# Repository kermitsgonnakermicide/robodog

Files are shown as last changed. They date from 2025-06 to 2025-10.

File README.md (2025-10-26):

# OpenDoggo

A quadruped robot platform running ROS2 Humble on a Raspberry Pi 4 with 3DOF legs and an optional SLAM capability via either Lidar and stereo vision.<br>

**Design**<br>
I started off by CADing the entire thing, keeping in mind that this will be an actively developed platform — no fancy covers, just raw plate and servo mounts.<br>
Went with a central plate that houses all the power distribution + electronics, and simple oval-style end mounts for the legs.<br>
The legs are 3DOF and use MG996R servos — cheap and decently powerful<br>
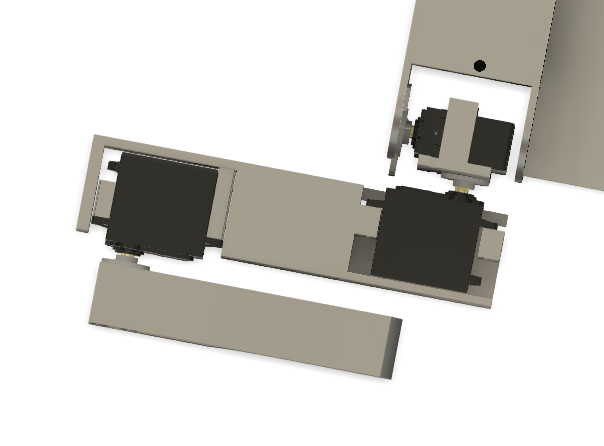
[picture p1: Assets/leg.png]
leg
<br>

Later added a lid to keep things _mostly_ protected.<br>
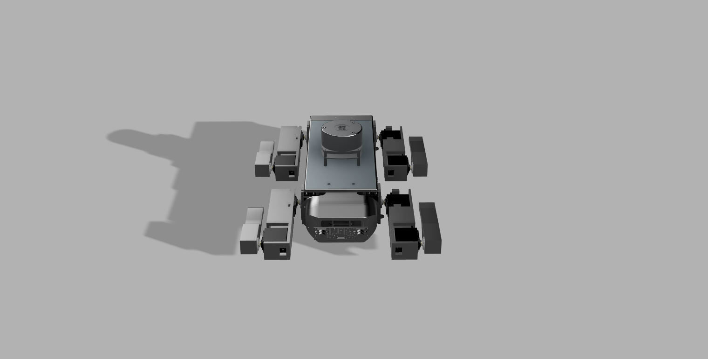
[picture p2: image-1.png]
<alt text>
<br>

**Electronics**<br>
I made a custom, 63 by 48 mm PCBA that has 5 major functions:<BR>

- step down power from my 4s 14.8v lipo battery to 5v<br>
- step up power from 5v to 7v to effectively power my servoes
- output that 5v power to my raspi on USB<br>
- control my servoes with a PCA9685<br>
- one of the best IMUs, the BNO086 for optimizing gait<br>
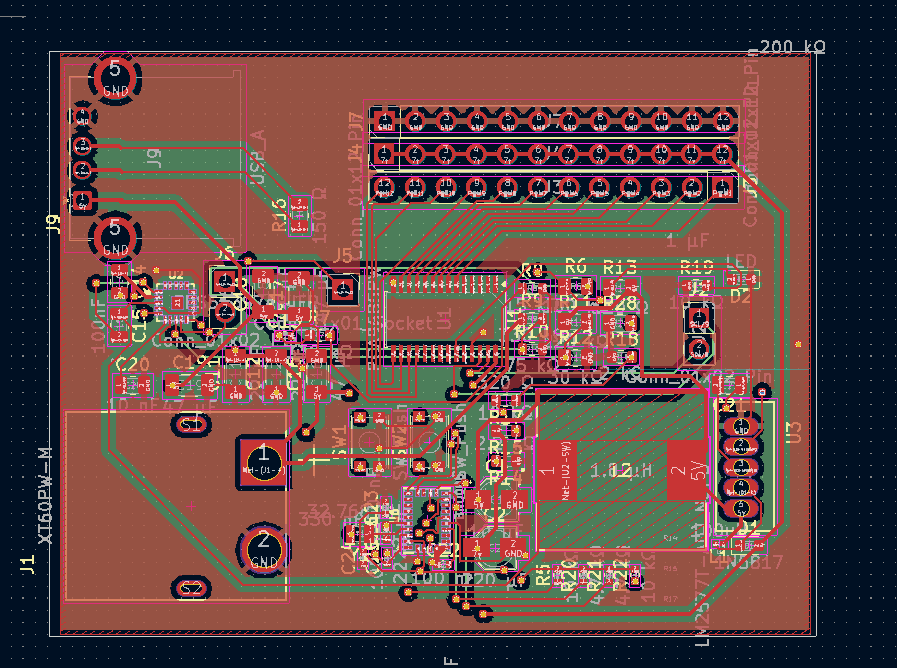
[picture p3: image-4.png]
  
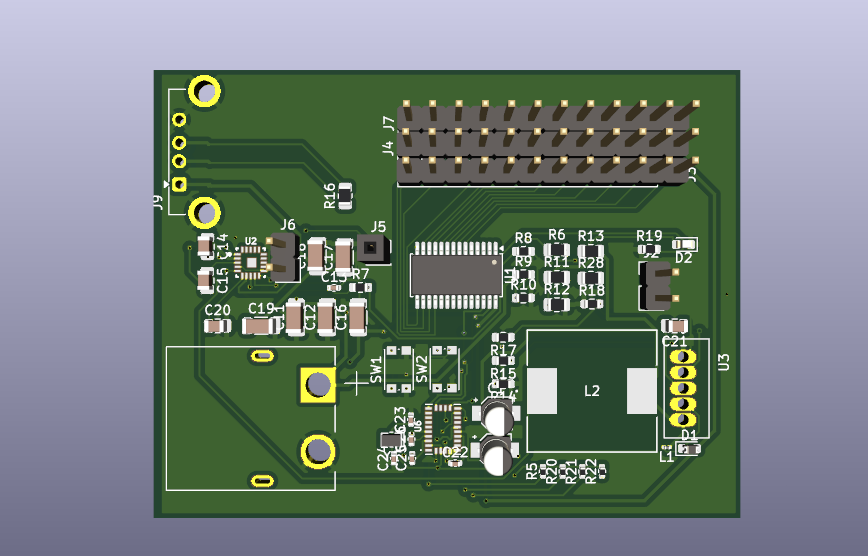
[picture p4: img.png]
  
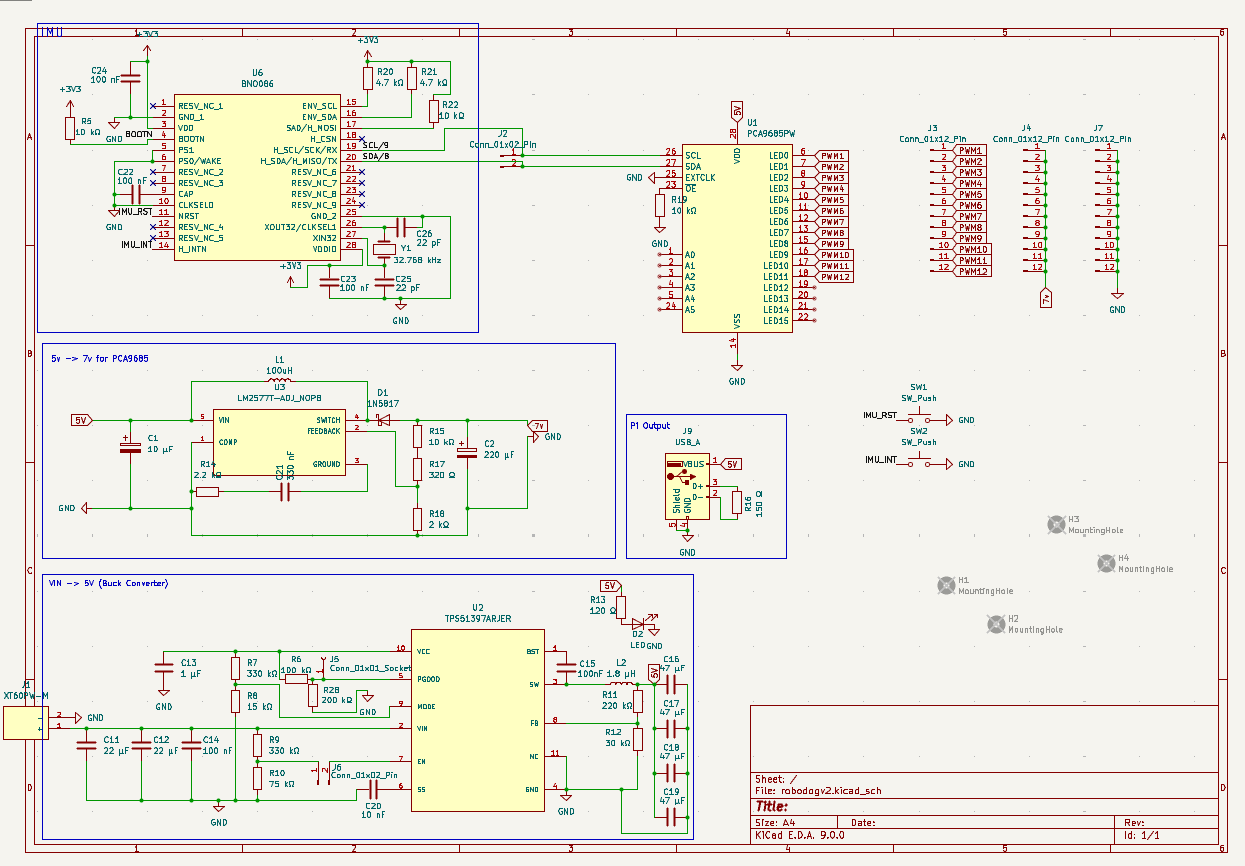
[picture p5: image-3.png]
  

**Firmware**<br>
**ROS Packages**  
The whole ROS workspace is structured into 4 main packages:

- **servo_driver**  
  The hardware interface layer. This node communicates with one or more PCA9685 boards via I2C to send position signals to each servo motor. It exposes a simple ROS2 service + topic interface that allows other nodes to command joint angles (in degrees or radians). It also implements basic limits, deadzone filtering, and optional torque hold toggling. Each servo is mapped to a specific joint name and leg index.

- **leg_walker**  
  This package does all the IK heavy lifting. It:

  - Subscribes to target paw positions (either via a `/cmd_paw_pos` topic or internal walking scripts)
  - Solves 3DOF inverse kinematics per leg (coxa, femur, tibia)
  - Publishes joint angles to the `servo_driver`
  - Supports gait generation — currently just a trot gait, but it's modular
  - Includes walking state machines, leg timing, and paw trajectory interpolation
    This is where all the math happens.

- **slam_yplidar_x2**  
  SLAM package using the YDLidar X2. It launches:

  - A serial connection to the Lidar via `ydlidar_ros2_driver`
  - `slam_toolbox` in synchronous mode
  - RViz config for map + robot visualization
    Outputs a 2D occupancy map and robot pose estimate. Currently uses fake odom + map merging but will be upgraded later with IMU + gait odometry.

- **slam_stereo_picams**  
  Alternate SLAM method using two Raspberry Pi cameras as a stereo pair (synced via GPIO trigger). It:
  - Captures stereo image pairs
  - Runs semi-global block matching or other stereo algorithm (WIP: OpenCV + rtabmap)
  - Feeds into `rtabmap_ros` for visual SLAM
  - Outputs a 3D point cloud and pose estimate
    This is mostly experimental right now but promising for GPS-denied areas and outdoor mapping.

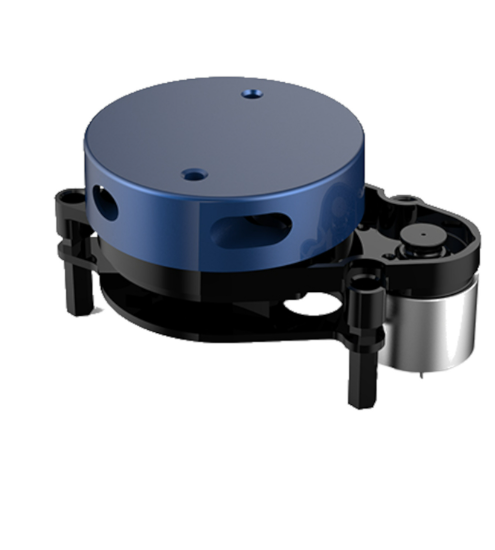
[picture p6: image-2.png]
alt text>
<br>

**NOTE**: Reusing the lipo battery from a diff project<br>

**BOM**
|ITEM |QTY|TOTAL |SRC |NOTES |
|---|---|---|---|---|
|Raspberry Pi 5 8GB |1 |94.82 |https://www.silverlineelectronics.in/collections/raspberry-pi-5-official-accessories/products/raspberry-pi-5-model-b-8gb-ram |I require an 8GB because I dont just need to use ROS - within it, I also need to do SLAM(even more computationally expensive)|
|RPi 5 Active Cooler |1 |5.27 |https://www.silverlineelectronics.in/collections/raspberry-pi-cooling-tech | |
|SD Card |1 |6.93 |https://www.amazon.in/SAMSUNG-Adaptor-Expanded-Storage-MB-MC64SA/dp/B0CXJ5Q222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,aps,226&sr=8-3&th=1| |
|Waveshare Stereo Camera|1 |47.76 |https://hubtronics.in/imx219-83-stereo-camera | |
|YDLIDAR X2 |1 |60.99 |https://www.electronicscomp.com/ydlidar-x2-360-degree-ros-scanner-for-navigation-collision-avoidance-8m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 | |
|PCBA |1 |129 |https://hc-cdn.hel1.your-objectstorage.com/s/v3/cd5c9a744fc6b144acc7592c6a4c4ebfb7888e05_image.png |LionCircuits |
|XT60PW-m |1 |1.91 |https://www.drkstore.in/amass-xt60pw-f20-connector/ |Not available to procure on LionCircuits, also including delivery |
|USB A |1 |0.17 |https://robu.in/product/u221-041n-1wr69-s5-xkb-1-5a-1-4p-female-40%e2%84%8385%e2%84%83-type-a-plugin-usb-connectors-rohs/ |Will cover myself, not available on LionCircuits |
|MG996R |12 |48.62 |https://sharvielectronics.com/product/mg996r-metal-gear-servo-motor/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 | |
| | | | | |
| | | | | |
| | |395.47| | |
**NOTE: Will also cover the MG996s myself to ensure that i'm under budget**

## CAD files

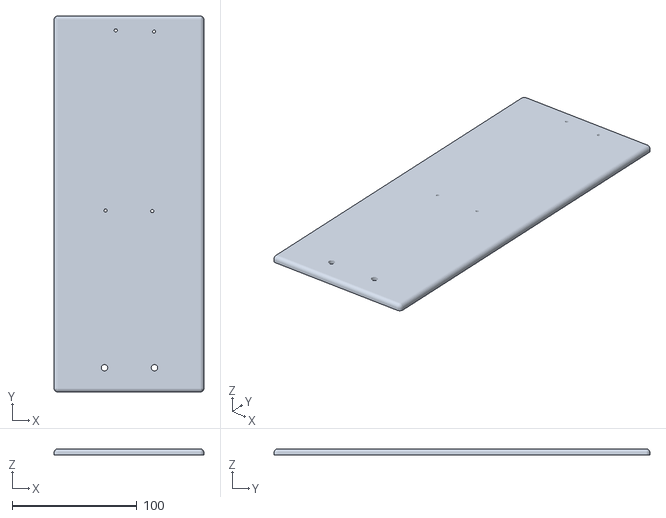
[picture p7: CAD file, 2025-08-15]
Production/Prints/MAINBODY_TOPPLATE.stl
120.0 x 301.0 x 5.00

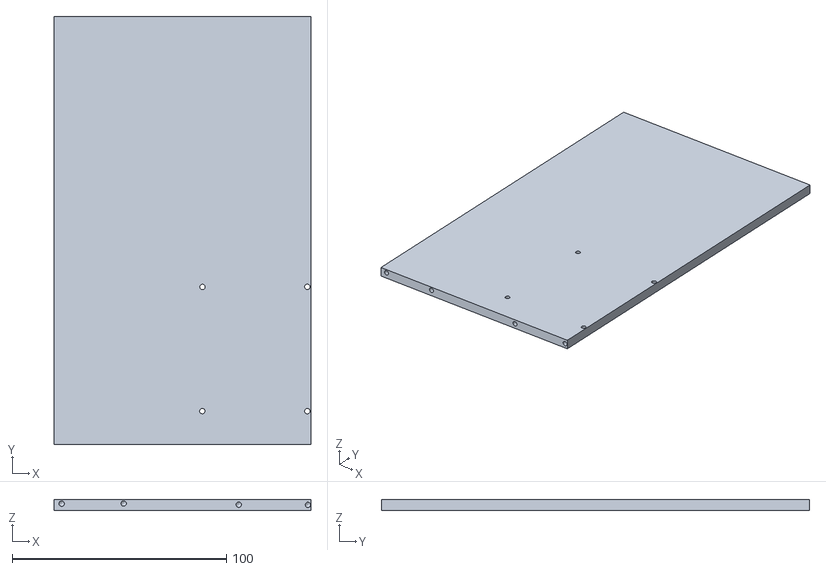
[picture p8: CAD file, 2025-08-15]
Production/Prints/MAINBODY_BOTTOMPLATE.stl
120.0 x 200.0 x 5.00

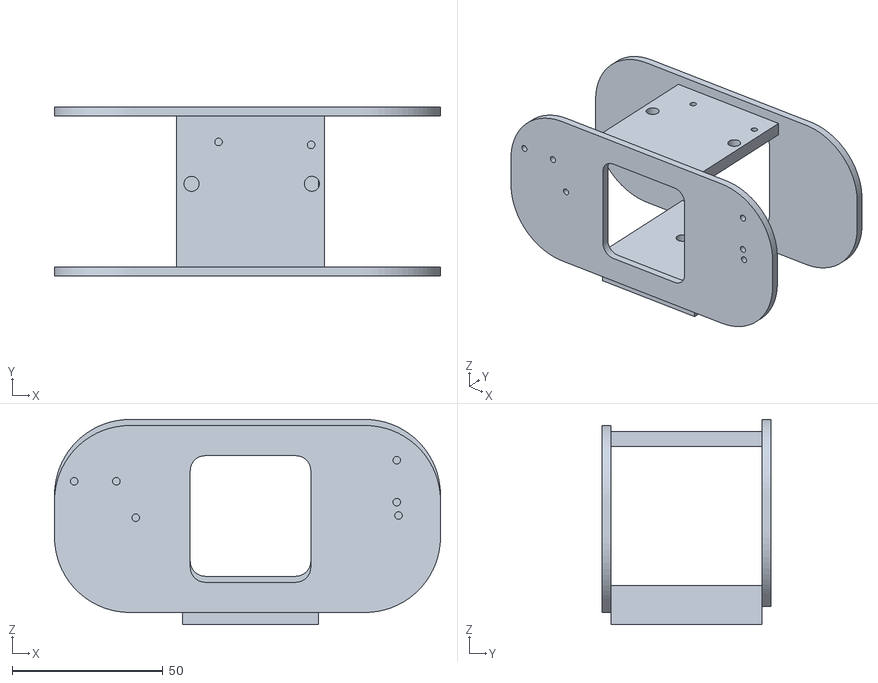
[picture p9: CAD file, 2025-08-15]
Production/Prints/MAINBODY_BACKMOUNTING.stl
128.0 x 56.0 x 68.0

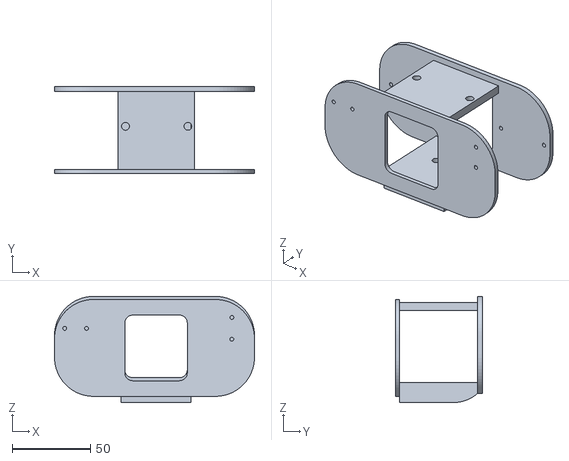
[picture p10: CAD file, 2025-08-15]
Production/Prints/MAINBODY_FRONTHING.stl
128.0 x 55.6 x 68.0

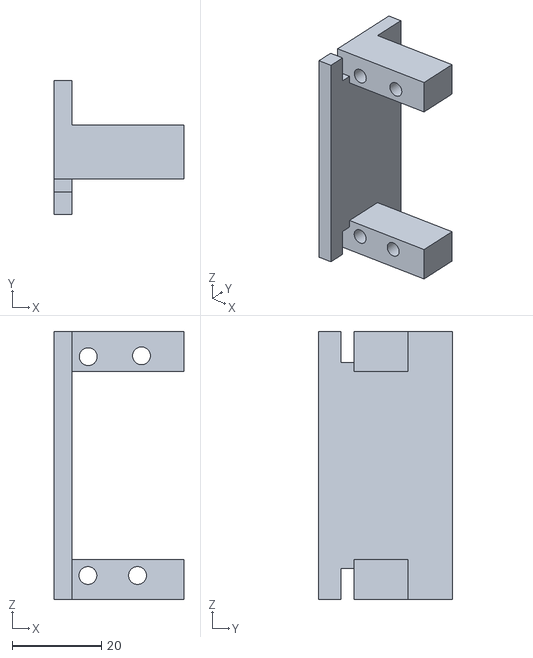
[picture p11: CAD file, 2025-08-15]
Production/Prints/LJ1(x4).stl
29.0 x 30.0 x 60.0

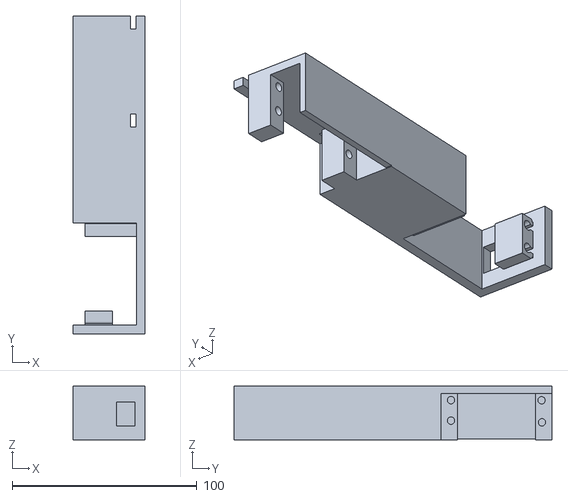
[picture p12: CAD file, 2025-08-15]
Production/Prints/LJ2(x4).stl
39.0 x 172.0 x 29.0

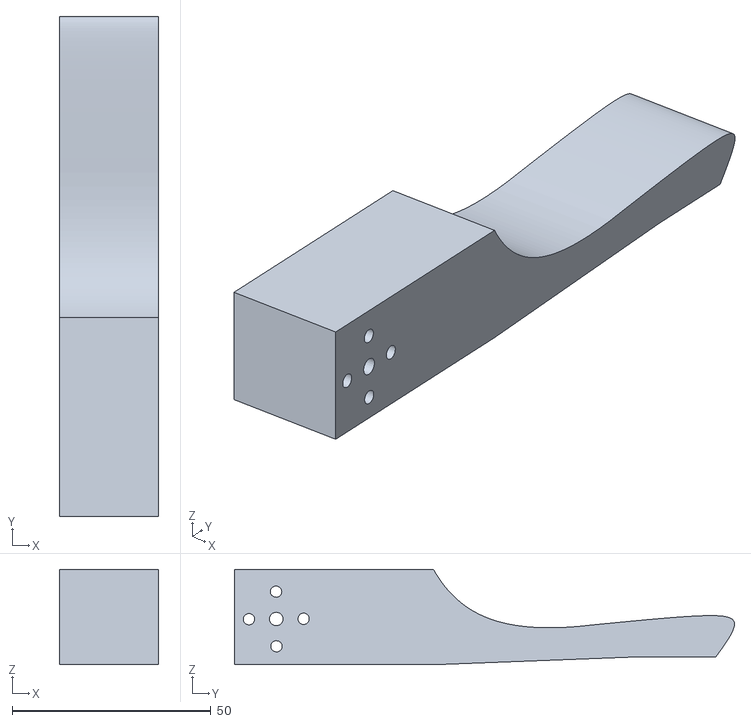
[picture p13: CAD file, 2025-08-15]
Production/Prints/LJ3(x4).stl
25.0 x 125.7 x 24.0

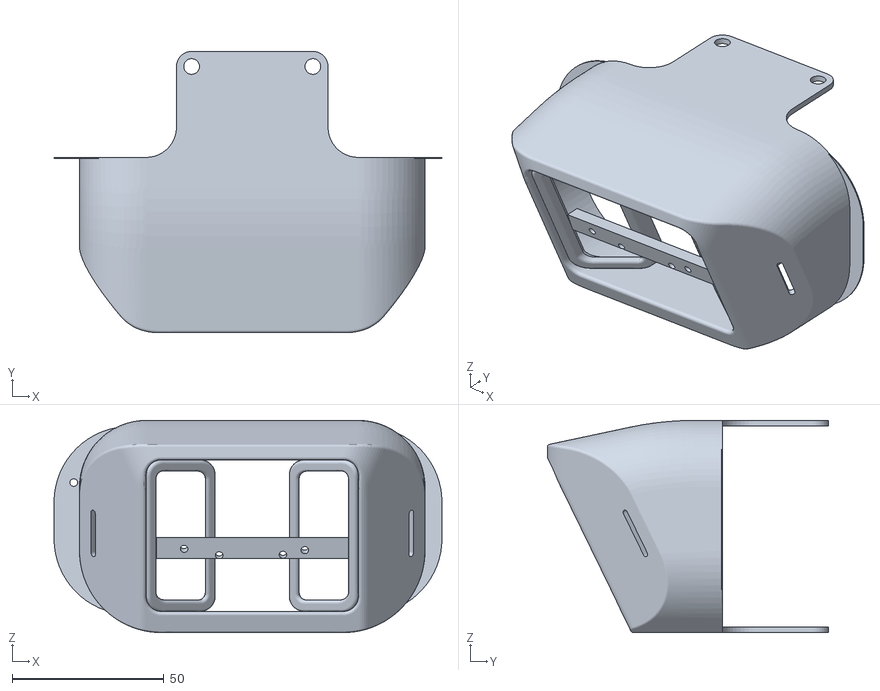
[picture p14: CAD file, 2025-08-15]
Production/Prints/HEAD.stl
128.0 x 92.8 x 70.0

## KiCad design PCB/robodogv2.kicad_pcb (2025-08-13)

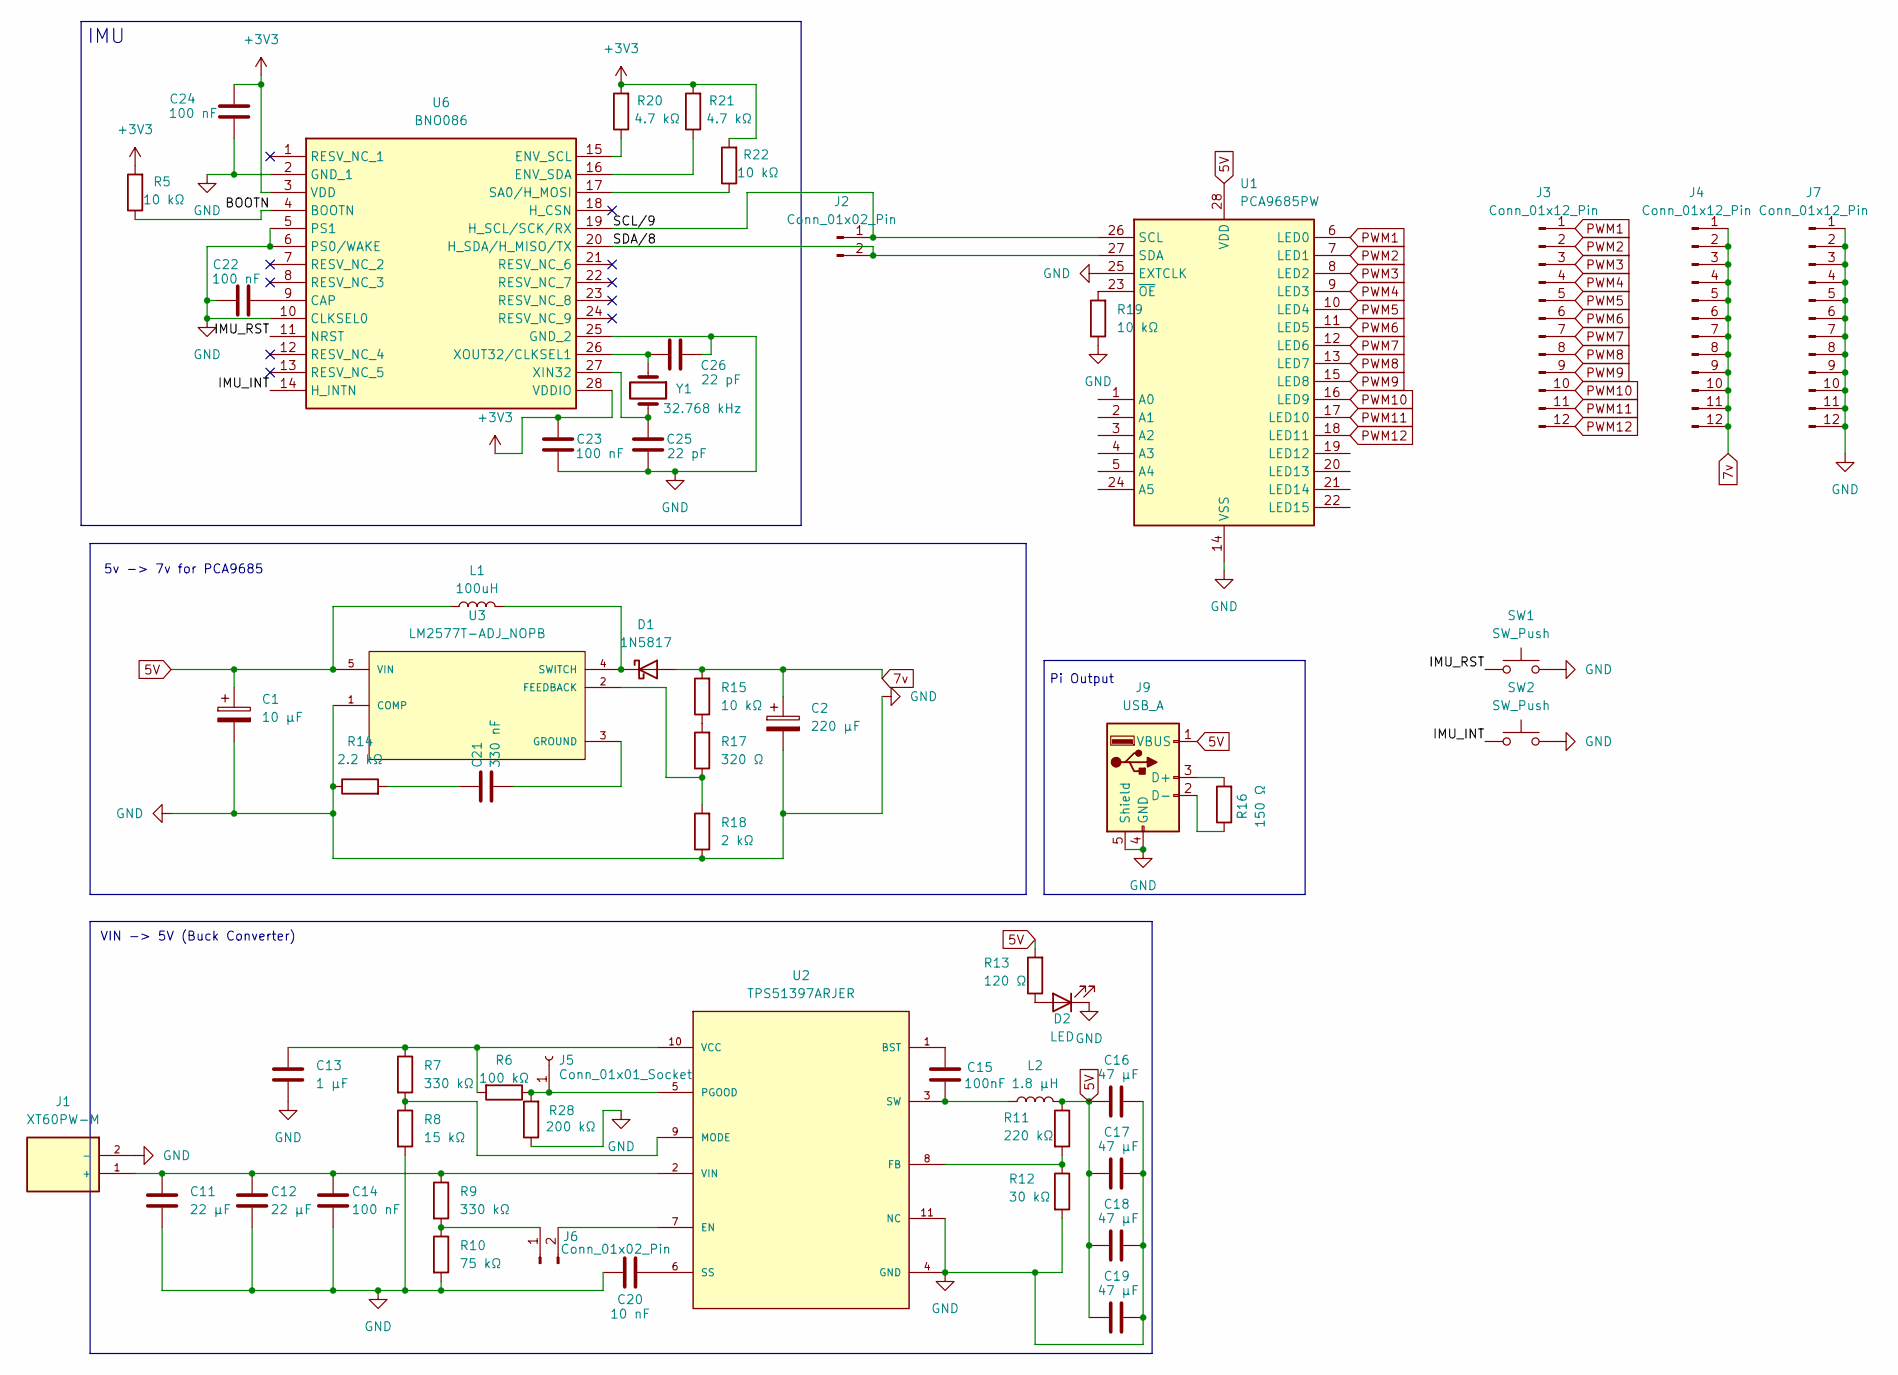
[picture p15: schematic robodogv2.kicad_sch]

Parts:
C1: 10 μF; CP_Elec_3x5.3
C2: 220 μF; CP_Elec_3x5.3
C11, C12: 22 μF; C_1206_3216Metric
C13: 1 μF; C_0402_1005Metric
C14: 100 nF; C_0805_2012Metric
C15: 100nF; C_0805_2012Metric
C16, C17, C18, C19: 47 μF; C_1206_3216Metric
C20: 10 nF; C_0805_2012Metric
C21: 330 nF; C_0805_2012Metric
C22, C23, C24: 100 nF; C_0402_1005Metric
C25, C26: 22 pF; C_0402_1005Metric
D1: 1N5817; D_0603_1608Metric
D2: LED; LED_0603_1608Metric
J1: XT60PW-M; AMASS_XT60PW-M; PARTREV V1.2
J2, J6: Conn_01x02_Pin; PinHeader_1x02_P2.54mm_Vertical
J3, J4, J7: Conn_01x12_Pin; PinHeader_1x12_P2.54mm_Vertical
J5: Conn_01x01_Socket; PinSocket_1x01_P2.54mm_Vertical
J9: USB_A; USB_A_Connfly_DS1095
L1: 100uH; L_0201_0603Metric
L2: 1.8 μH; IND_IHLP_5050_FD_VIS
R5, R22: 10 kΩ; R_0402_1005Metric
R6: 100 kΩ; R_0805_2012Metric
R7, R9: 330 kΩ; R_0603_1608Metric
R8: 15 kΩ; R_0603_1608Metric
R10: 75 kΩ; R_0603_1608Metric
R11: 220 kΩ; R_0805_2012Metric
R12: 30 kΩ; R_0805_2012Metric
R13: 120 Ω; R_0805_2012Metric
R14: 2.2 kΩ; R_0603_1608Metric
R15, R19: 10 kΩ; R_0603_1608Metric
R16: 150 Ω; R_0805_2012Metric
R17: 320 Ω; R_0603_1608Metric
R18: 2 kΩ; R_0603_1608Metric
R20, R21: 4.7 kΩ; R_0402_1005Metric
R28: 200 kΩ; R_0805_2012Metric
SW1, SW2: SW_Push; SW_Push_1P1T_NO_CK_KMR2
U1: PCA9685PW; TSSOP-28_4.4x9.7mm_P0.65mm
U2: TPS51397ARJER; RJE0020B-MFG
U3: LM2577T-ADJ_NOPB; VREG_LM2577T-ADJ_NOPB; PARTREV D
U6: BNO086; IC_BNO086
Y1: 32.768 kHz; Crystal_SMD_MicroCrystal_CC8V-T1A-2Pin_2.0x1.2mm

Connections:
5V: C1.1, C16.1, C17.1, C18.1, C19.1, J9.1 (VBUS), L1.1, L2.2, R11.1, R13.2, U1.28 (VDD), U3.5 (VIN)
7v: C2.1, D1.2 (A), J4.1, J4.2, J4.3, J4.4, J4.5, J4.6, J4.7, J4.8, J4.9, J4.10, J4.11, J4.12, R15.2
+3V3: C23.1, C24.2, R5.2, R20.2, R21.2, R22.2, U6.3 (VDD), U6.28 (VDDIO)
/BOOTN: R5.1, U6.4 (BOOTN)
/IMU_INT: SW2.1, U6.14 (H_INTN)
/IMU_RST: SW1.1, U6.11 (NRST)
/SCL/9: J2.1, U1.26 (SCL), U6.19 (H_SCL/SCK/RX)
/SDA/8: J2.2, U1.27 (SDA), U6.20 (H_SDA/H_MISO/TX)
GND: C1.2, C2.2, C11.1, C12.1, C13.2, C14.2, C16.2, C17.2, C18.2, C19.2, C20.2, C22.1, C23.2, C24.1, C25.2, C26.2, D2.1 (K), J1.2 (-), J7.1, J7.2, J7.3, J7.4, J7.5, J7.6, J7.7, J7.8, J7.9, J7.10, J7.11, J7.12, J9.4 (GND), J9.5 (Shield), R8.2, R10.2, R12.2, R14.1, R18.1, R19.1, R28.1, SW1.2, SW2.2, U1.14 (VSS), U1.25 (EXTCLK), U2.4 (GND), U2.11 (NC), U3.1 (COMP), U6.2 (GND_1), U6.5 (PS1), U6.6 (PS0/WAKE), U6.10 (CLKSEL0), U6.25 (GND_2)
unnamed: C21.1, R14.2
unnamed: D1.1 (K), L1.2, U3.4 (SWITCH)
unnamed: D2.2 (A), R13.1
unnamed: C11.2, C12.2, C14.1, J1.1 (+), R9.1, U2.2 (VIN)
unnamed: J5.1, R6.1, R28.2, U2.5 (PGOOD)
unnamed: J6.1, R9.2, R10.1
unnamed: J6.2, U2.7 (EN)
unnamed: J9.3 (D+), R16.2
unnamed: J9.2 (D-), R16.1
unnamed: R15.1, R17.2
unnamed: R19.2, U1.23 (~OE)
unnamed: C15.2, U2.1 (BST)
unnamed: R11.2, R12.1, U2.8 (FB)
unnamed: R7.2, R8.1, U2.9 (MODE)
unnamed: C20.1, U2.6 (SS)
unnamed: C15.1, L2.1, U2.3 (SW)
unnamed: C13.1, R6.2, R7.1, U2.10 (VCC)
unnamed: R17.1, R18.2, U3.2 (FEEDBACK)
unnamed: C21.2, U3.3 (GROUND)
unnamed: C22.2, U6.9 (CAP)
unnamed: R20.1, U6.15 (ENV_SCL)
unnamed: R21.1, U6.16 (ENV_SDA)
unnamed: R22.1, U6.17 (SA0/H_MOSI)
unnamed: C25.1, U6.27 (XIN32), Y1.2
unnamed: C26.1, U6.26 (XOUT32/CLKSEL1), Y1.1
PWM1: J3.1, U1.6 (LED0)
PWM2: J3.2, U1.7 (LED1)
PWM3: J3.3, U1.8 (LED2)
PWM4: J3.4, U1.9 (LED3)
PWM5: J3.5, U1.10 (LED4)
PWM6: J3.6, U1.11 (LED5)
PWM7: J3.7, U1.12 (LED6)
PWM8: J3.8, U1.13 (LED7)
PWM9: J3.9, U1.15 (LED8)
PWM10: J3.10, U1.16 (LED9)
PWM11: J3.11, U1.17 (LED10)
PWM12: J3.12, U1.18 (LED11)

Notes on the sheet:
5v -> 7v for PCA9685
VIN -> 5V (Buck Converter)
IMU
Pi Output

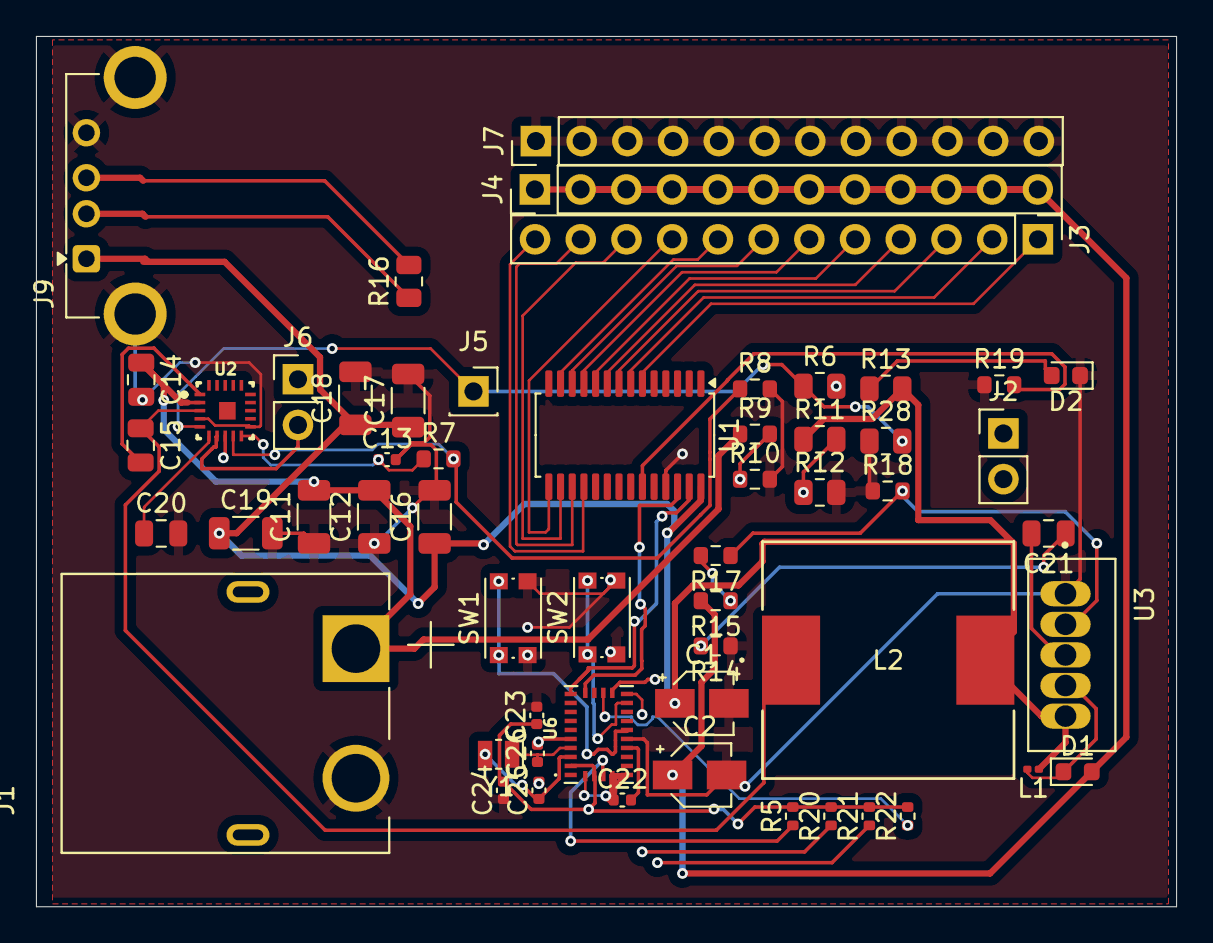
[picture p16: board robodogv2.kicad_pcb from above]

Board: 4 copper layers, 63.3 x 48.3 mm, 56 parts (0 on the bottom side), 46 nets.

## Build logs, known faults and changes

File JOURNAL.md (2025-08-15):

**Total Time: 32.5hrs**

# June 11th-12th: Fully CADed

Started off the project by launching Fusion 360 and blocking out the dog's main chassis. My main goal here was **functional simplicity** — something that’s easy to assemble, modify, and mount hardware on without disassembling half the bot every time i want to add/remove something.

The design I landed on has:

- A **flat center plate** that acts as the main body, made wide enough to comfortably hold the Pi, power distribution boards, battery, GPS, and (hopefully) a lidar
- **Two rounded end plates** — just simple ovals that hold the servo brackets in place for each leg. These are symmetric and bolt straight onto the side of the center plate
- Leg brackets aligned vertically to simplify the IK — each leg has a clean coordinate frame, and the coxa (hip) servo only rotates in one axis

The whole CAD is parametric, so I can tweak servo spacing or leg lengths later without rebuilding everything.

For now, I decided **not** to CAD any decorative shells or aesthetic casings — this robot is going to get opened and torn apart regularly as I iterate.

The legs themselves are **3DOF**, made up of:

- Coxa (horizontal rotation)
- Femur (up/down swing)
- Tibia (final linkage)

I'm using **MG996R servos** for all joints. They’re not ideal — big dead zones, analog feedback, and can burn out under load — but for their price and torque (~10kg-cm), they’re a solid starting point for a dev platform.

leg

At this point, I’m happy with the mechanical design — but it took way longer than expected (I’m 3 redbulls deep and fully aware that I should’ve sketched this on paper first, but I cannot draw).

**Time Spent: 15hrs**

---

# June 13th - Schematic

Did the full schematic layout for wiring everything together.

The build doesn’t use a custom PCB (at least not yet), so this schematic was mostly to organize:

- 12x MG996R servos (3 per leg)
- 1x PCA9685 servo driver
- Pi 4 power via USB boost board
- Optional second PCA driver for expansion

Used the schematic as a build reference, mainly so I don’t fry something expensive.<br>
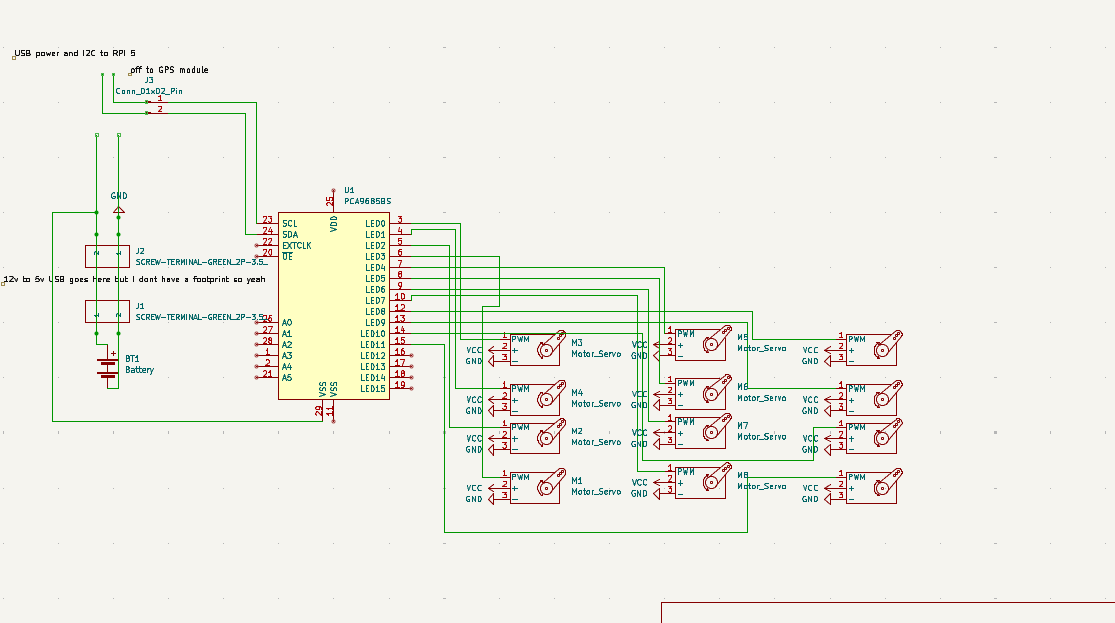
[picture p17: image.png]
<br>
**Time Spent: 2hr**

---

# June 14th - Firmware Pt1

Finally jumped into the firmware side — specifically the **inverse kinematics (IK)** solver.

I started with basic 2D planar IK just to get a feel for how the math works. Then gradually added complexity:

- Each leg is modeled as a 3-link manipulator
- The joints are offset in real 3D space but constrained to operate on a 2D plane per leg
- Used basic trigonometry — cosine law, sine law — to solve for femur and tibia angles
- The coxa joint is just a simple `atan2(y, x)` to find the rotation from the robot’s center to the leg’s target

The trickiest bit was solving for reachable vs. unreachable points — since these are cheap servos, they can't actually hold position reliably under tension. So I added a soft clamping system that limits paw positions to a safe working volume per leg.

Once the math was stable, I built a standalone Python test script that:

- Lets you type in an XYZ paw coordinate
- Solves and visualizes the joint angles
- Outputs the result in degrees, ready to be piped to the servo driver later

Also added some forward kinematics functions so I can sanity-check the solved angles (and catch bugs in weird limb configs).

Next: wrap this math in a ROS node.

**Time Spent: 5hr**

---

# June 17th - Updated CAD and Finished Firmware

Added a lid! The barebones open-top chassis was good for dev, but I was worried about connector damage or shorting stuff on the metal servo cases. So: added a snap-on lid.<br>
<alt text>

Finished the Python-based firmware:

- IK engine is now stable and modular
- It supports per-leg calibration offsets
- Outputs angle commands in degrees (for PCA9685)

Next step: slap it into ROS.<br>
**Time Spent: 4hr**

---

# June 17th-18th - ROS TIME BAYBEEEEEEEEEEE!

Wrapped up the ROS2 workspace! This was the big milestone. The whole project is now structured as 4 packages:

1. **servo_driver** – I2C interface to PCA9685, angle commands, watchdog safety.
2. **leg_walker** – IK per leg, gait generation, coordinated trajectories.
3. **slam_yplidar_x2** – 2D SLAM pipeline with YDLidar X2 + slam_toolbox.
4. **slam_stereo_picams** – WIP stereo depth + SLAM for outdoor mapping.

This structure keeps hardware control, locomotion logic, and perception modules separate — easier to maintain and swap out later.
alt text><br>
**Time Spent: 2hr**

# August 10th - PCB time _bruh_

alright so it appears I do HAVE to make a PCB, so I kinda slapped everything I could on there - servo control, power and even an IMU for stabilizing the robot(integrated into my gait stuff in ROS)<br>
I used a BNO086 for the IMU, a PCA9685 for servo control and this super cool ic, the TPS51397ARJER for power(anything VIN to 5v!!) reccomended to me by my friend aarav<br>
This is also SUPER small, so this should make our situation much more compact on the dog<br>



**Time Spent: 4.5hr**

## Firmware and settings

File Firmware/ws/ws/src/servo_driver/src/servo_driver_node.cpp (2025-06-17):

#include <rclcpp/rclcpp.hpp>
#include <sensor_msgs/msg/joint_state.hpp>
#include "servo_driver/pwm_controller.hpp"

PCA9685 driver0(0x40);
PCA9685 driver1(0x41);

std::map<std::string, std::pair<int, int>> joint_map = {
  {"leg1_rot", {0x40, 0}}, {"leg1_up", {0x40, 1}}, {"leg1_low", {0x40, 2}},
  {"leg2_rot", {0x40, 3}}, {"leg2_up", {0x40, 4}}, {"leg2_low", {0x40, 5}},
  {"leg3_rot", {0x41, 0}}, {"leg3_up", {0x41, 1}}, {"leg3_low", {0x41, 2}},
  {"leg4_rot", {0x41, 3}}, {"leg4_up", {0x41, 4}}, {"leg4_low", {0x41, 5}}
};

class ServoDriver : public rclcpp::Node {
public:
  ServoDriver() : Node("servo_driver") {
    sub_ = create_subscription<sensor_msgs::msg::JointState>(
      "joint_states", 10,
      std::bind(&ServoDriver::callback, this, std::placeholders::_1)
    );
    driver0.setPWMFreq(50);
    driver1.setPWMFreq(50);
  }

  void callback(const sensor_msgs::msg::JointState::SharedPtr msg) {
    for (size_t i = 0; i < msg->name.size(); i++) {
      auto name = msg->name[i];
      float angle = msg->position[i];
      if (!joint_map.count(name)) continue;

      auto [addr, ch] = joint_map[name];
      if (addr == 0x40)
        driver0.setAngle(ch, angle);
      else
        driver1.setAngle(ch, angle);
    }
  }

private:
  rclcpp::Subscription<sensor_msgs::msg::JointState>::SharedPtr sub_;
};

int main(int argc, char **argv) {
  rclcpp::init(argc, argv);
  rclcpp::spin(std::make_shared<ServoDriver>());
  rclcpp::shutdown();
  return 0;
}

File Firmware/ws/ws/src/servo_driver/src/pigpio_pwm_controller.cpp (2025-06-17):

#include "servo_driver/pigpio_pwm_controller.hpp"
#include <stdexcept>
#include <unistd.h>

PCA9685::PCA9685(int i2c_addr) : i2c_addr_(i2c_addr) {
  if (gpioInitialise() < 0) {
    throw std::runtime_error("pigpio init failed");
  }

  handle_ = i2cOpen(1, i2c_addr_, 0);
  if (handle_ < 0) {
    throw std::runtime_error("Failed to open I2C");
  }

  i2cWriteByteData(handle_, 0x00, 0x00); // MODE1 reset
  setPWMFreq(50);
}

PCA9685::~PCA9685() {
  i2cClose(handle_);
  gpioTerminate();
}

void PCA9685::setPWMFreq(int freq) {
  float prescaleval = 25000000.0 / (4096.0 * freq) - 1.0;
  uint8_t prescale = static_cast<uint8_t>(prescaleval + 0.5);

  uint8_t oldmode = i2cReadByteData(handle_, 0x00);
  uint8_t newmode = (oldmode & 0x7F) | 0x10;

  i2cWriteByteData(handle_, 0x00, newmode);
  i2cWriteByteData(handle_, 0xFE, prescale);
  i2cWriteByteData(handle_, 0x00, oldmode);
  usleep(5000);
  i2cWriteByteData(handle_, 0x00, oldmode | 0xA1);
}

void PCA9685::setPWM(int channel, int on, int off) {
  i2cWriteByteData(handle_, 0x06 + 4 * channel, on & 0xFF);
  i2cWriteByteData(handle_, 0x07 + 4 * channel, on >> 8);
  i2cWriteByteData(handle_, 0x08 + 4 * channel, off & 0xFF);
  i2cWriteByteData(handle_, 0x09 + 4 * channel, off >> 8);
}

void PCA9685::setAngle(int channel, float angle) {
  float deg = angle * 180.0 / M_PI;
  float pulse = 1500 + (deg / 90.0) * 1000;
  int ticks = static_cast<int>(pulse / 20000.0 * 4096);
  setPWM(channel, 0, ticks);
}

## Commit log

2025-06-17 FUNWARE FINALYY YEYAYAYAYAYAYA
    [servo_map.yaml]
2025-06-23 finaalalalalaaaaaaaaaaaaaaa!!!!
    baguettee
    [BOM.csv]
